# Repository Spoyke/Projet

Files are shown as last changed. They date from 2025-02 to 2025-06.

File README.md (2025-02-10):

# Projet
Ce projet vise à créer deux énigmes sur un cube. L'un comportera un message à déchiffrer un code et l'écrire sur un codex et le second consiste à aligner des miroirs pour diriger des faisceaux lasers sur des capteurs.  

Intro:
L’idée est de créer un cube comportant 4 énigmes permettant d’obtenir 3 clefs pour activer un mécanisme à la fin.
La Team A s’occupe de la face du haut, la Team B s’occupe d’une face latérale et la Team C nous nous occupons de deux face latérales et de la face ou l’on insère les clefs.
Notre première face comporte un codex et est relié à une seconde face qui est un parcours de lasers.

IMG CODEX

La partie avec le codex reprend des mécaniques simples mais efficaces des jeux d’énigmes. Cette partie du cube fera tout d’abord clignoter une LED. Et, un message codé se cache dans les clignotements de la LED. L’utilisateur devra donc décoder le message grâce à un tableau de correspondance inscrit quelque part sur le cube. Une fois le message décodé, le joueur n’a plus qu’à le reporter sur le codex de la face. Et si le message est correct, un mécanisme s’enclenche et débloque la seconde face de l’énigme avec les lasers. 

Techniquement, cette face comporte 2 éléments propres : une LED et un codex. La LED est directement reliée à une stm qui fera constamment clignoter le message. Et, le codex est constitué de plusieurs roues. Chacune des roues comprend une lettre du message. Si toutes les roues sont tournées dans le bon sens, un faisceau laser passe à travers ce dernier et est redirigé vers la seconde face de l’énigme. 

IMG LASER

La face avec les lasers comporte 4 lasers qui clignotent à différente fréquence invisible à l'œil nu afin de les différencier. Nous avons besoin de 4 capteurs capables d'identifier différents niveaux de clignotement.
Le but comme vous pouvez le voir sur l’image ci-dessus est de créer 4 parcours différents plus ou moins simple avec des obstacles pour ajouter de la difficulté aux parcours. 
Afin d’orienter les lasers nous utilisons des miroires, les tige qui s’enfonce dans le quadrillage seront crantée afin d'éviter une rotation sous le poids.(cela sera etudiee pour etre sur de l’utilité)

L’énigme une fois réussie ouvre une trappe pour avoir la clef, elle peut être résolution si et seulement si les lasers sont en face des bon capteurs.

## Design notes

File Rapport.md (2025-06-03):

# Partie informatique

## 1. Objectif général

Cette partie du projet vise à gérer la logique de l’énigme via un microcontrôleur STM32. Le programme contrôle une LED affichant un mot en morse, lit un phototransistor pour vérifier la position d’un "codex", et commande un moteur (via PWM) permettant l’ouverture d’une boîte contenant une clé.

## 2. Configuration matérielle

Avant le développement logiciel, une configuration matérielle du microcontrôleur est nécessaire en fonction des besoins du système.

### Ressources utilisées :

#### Configuration générale

| Fonction | Broche | Configuration | Détail |
|---|---|---|---|
| LED morse | PA10 | GPIO_Output | Contrôle de l'affichage en morse  |
| Bouton de déclenchement | PA4 | GPIO_Input | Détection de l'appui utilisateur |
| Lecture du phototransistor | PA3 | ADC | Vérification de la résolution du codex |
| Commande du moteur | PA9 | PWM | Contrôle de l'ouverture de la boîte |

#### Configuration des composants

Il y a deux timers dans le projet. Un (tim2) pour faire fonctionner le code. Nous verrons son utilité dans la partie "Structure logicielle". Le second timer (tim1) génère le signal PWM permettant de contrôler les moteurs. 

Le timer 2 est paramétré pour généré une interruption toute les millisecondes (PSC = 3 et ARR = 9999). Ce qui est largement suffisant pour notre programme qui dépend surtout de l'interaction avec l'utilisateur.

Tandis que le timer 1 est configuré pour générer un signal PWM sur le channel 2 (PA9) pour des raisons de débogage (PA8 soit channel 1 est aussi utilisé par la carte dans le mode debug). Par défaut, le timer possède un PSC de 3 et un ARR de 19999. Et, l'auto reload preload est activé.

L'adc est simplement activé sur IN8 (PA3).

## 3. Structure logicielle

Le programme fonctionne en simulant du multithreading. Chaque milliseconde, une interruption générée par le Timer 2 qui appelle successivement l'une des **4 fonctions du projet**, de manière cyclique.

### Les tâches sont les suivantes :

- **taskReadBtn**  
   Lit l’état du bouton utilisateur et met à jour la variable globale `motor_state`.

- **taskBlinkLed**  
   Gère l’affichage du message en morse via la LED, en fonction de `morse_btn_state`.

- **taskReadLed**  
   Lit la tension aux bornes du phototransistor via l’ADC. Si la tension dépasse un seuil, cela indique que le bon mot est affiché sur le codex.

-  **taskControlMotor**  
   Modifie le signal PWM selon l’état de l’énigme (`motor_state`), avec un délai d’une seconde pour éviter les activations accidentelles.

## 4. Détails de l’implémentation

### `main.c`

Le fichier "main" n'est utilisé uniquement pour initialiser les différent composants du projet : 

- Activation des interruptions (Timer 2)
- Lancement du signal PWM (Timer 1)

### `stm32l4xx_it.c`

Ce fichier comprend le cœur des fonctions du projet, exécuté à chaque interruption du Timer 2.

#### `taskReadBtn()`

Fonction simple mais essentielle :  
Elle lit l’état du bouton poussoir et met à jour la variable `morse_btn_state`. Cette variable déclenche ou interrompt la séquence Morse dans les autres fonctions.

#### `taskBlinkLed()`

Cette fonction affiche un mot en morse via une LED.  
- Des variables statiques gèrent le caractère affiché ainsi que sa durée d'exposition.
- À chaque appel, si le bouton a été pressé (`morse_btn_state == 1`), la LED clignote selon le code Morse définie dans une constante.
- En fin de message, les variables sont réinitialisées.

#### `taskReadLed()`

Fonction de lecture analogique :
- Lance une conversion ADC et attend la fin.
- Convertit la valeur lue (sur 12 bits, 0–4095) en tension via un produit en croix : $tension = \frac{100.Valeur~de~l'adc}{2^{12}}$. Ce qui permet d'avoir une valeur comprise entre 0 et 100 en sortie. On aurait pu multiplié par 5 pour obtenir la tensions aux bornes du photo-transistor en sortie, le choix de multiplié par 100 est purement arbitraire.
- Si la tension dépasse un seuil défini (ici 90), la variable globale `motor_state` est mise à 1 (sinon 0), indiquant que le codex a été résolu.

#### `taskControlMotor()`

Cette fonction gère le moteur via la PWM :
- Si `motor_state` passe à 1, on lance un compte à rebours d'une seconde avant de modifier le signal PWM.
- Cela évite que l’utilisateur n’active le moteur par hasard lors de la rotation du codex.
- Le PWM est modifié via `__HAL_TIM_SET_COMPARE()` en fonction de l’état validé.

Le rôle des moteurs dans l'énigme étant de simplement ouvrir ou fermé le prix. Ces derniers ne se situeront qu'au deux extrêmes possibles (0 ou 180°). C'est pourquoi, avec `__HAL_TIM_SET_COMPARE()`, nous paramétrons le signal pour qu'il soit sur un des deux extrêmes, c'est-à-dire une largeur de crénau de 10ms ou de 20ms.

NB : A savoir que lorsque l'on flash le code sur le microprocesseur, il faut ensuite couper l'alimentation de la carte avant de la remettre pour que le code prenne effet.

# Concernant le PCB

## 1. Enjeux du PCB

Pour le projet, nous avons besoin de créer un PCB qui respecte certaines conditions, comme le fait que nous prévoyons d’utiliser deux faces du cube et que nous sommes dans une démarche écologique, donc sans gaspillage.
Nous allons également avoir besoin d’utiliser des composants sans forcément les relier directement au PCB.

## 2. Disposition sur le PCB

### Pour la composition du PCB, nous avons besoin de plusieurs éléments :

- **Le microprocesseur**  
   Nous avons décidé d’utiliser le `STM32L412KBT6`, car il possède suffisamment de pins pour notre projet et nous permet de rester sur la gamme STM. Il sera accompagné de son connecteur afin de pouvoir téléverser le code.\
  _Nous utiliserons un réseau de trois condensateurs, 4,7 µF, 100 nF, et 100 nF, pour découpler l’alimentation générale.
Nous filtrerons également l’alimentation à l’aide d’un filtre LC, afin de la stabiliser. Ce filtre sera composé d’une inductance de 39 nH et de deux condensateurs de 1 µF et 10 nF, dans le but de filtrer les hautes fréquences et les parasites liés à la masse._

- **Les lasers**  
   Nous aurons besoin d’une partie dédiée aux lasers et à leurs récepteurs (utilisés dans la deuxième énigme). Le but de cette énigme est d’utiliser un jeu de miroirs pour rediriger les faisceaux vers leurs récepteurs, afin de résoudre l’énigme.\
   _Les lasers utilisé sont des `VMA434` et on besoins simplement du résistance de 270 ohms sur le pin d'information._

- **Le régulateur de tension**  
   Nous avons également besoin d’un régulateur de tension pour l’alimentation du PCB, nous utilisons un LDO, le `BU33SD5WG-TR`.\
   _Nous relierons le GND et le Vout par un condensateur de 1 µF, de même pour le Vin et le GND. Le Vin sera alimenté en 5 V et le Vout délivrera du 3,3 V._

- **Une seconde PCB sera fixée sur une autre face pour le fonctionnement du codex.**  
   Elle comprendra une LED (émetteur) qui, une fois le bon code trouvé sur notre codex, viendra éclairer un phototransistor (récepteur) en passant à travers de petits trous alignés dans les roues du codex. Il y aura également une LED qui affichera le code morse afin que l’utilisateur puisse le déchiffrer.\
  _Une résistance de 10 kΩ sera utilisée pour le phototransistor, ainsi que des résistances d’adaptation pour les LED : une de 580 Ω reliée à l’alimentation, et une autre de 420 Ω reliée au GND._

- **Deux boutons**  
   Un pour réinitialiser le code morse, et un autre pour réinitialiser le microcontrôleur (et donc les lasers également).\
   _Ils seront en montage push-pull, avec des resistance de 120 Ω._

- **Deux Servomoteurs**  
   Le premier permettra l’ouverture de la trappe pour accéder à la clé après la résolution de nos énigmes.
   Le second servira à ouvrir la boîte une fois toutes les énigmes résolues.
   Il suffit qu’ils tournent à 180° pour permettre une ouverture optimale.

- **Les clefs**  
   Nous avons besoin d’un accès au 5V et au GND afin d’interconnecter les différentes clés entre elles.

- **Infos importantes**  
   Comme tous les composants ne sont pas directement connectés au PCB, car ils doivent être placés à différents endroits, nous utilisons des connecteurs à la place des composants pour faciliter leur déport.\
  Des trous de fixation sont également prévus afin de pouvoir fixer nos PCB.

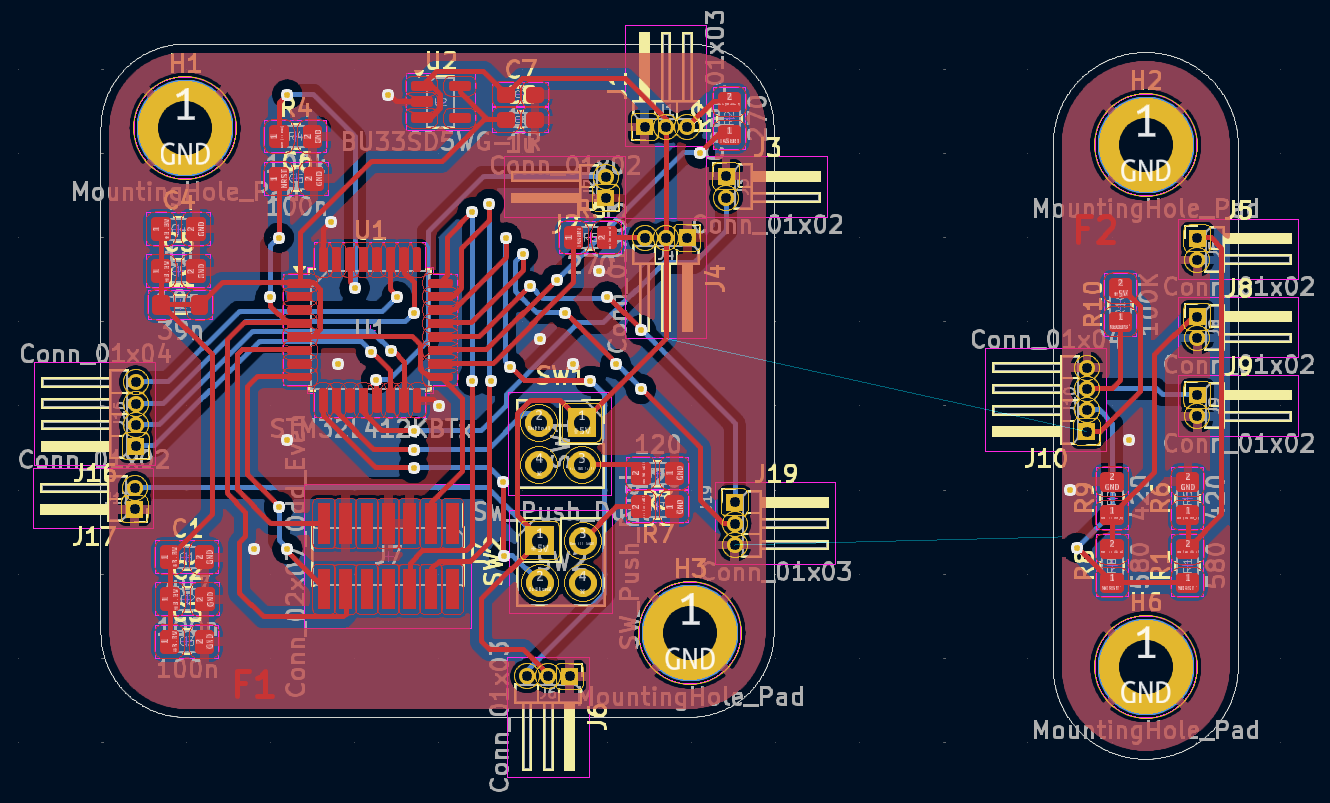
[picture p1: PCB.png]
 

# 3. Conception mécanique et assemblage

## 3.1 Objectif de conception

L’un des objectifs majeurs de notre projet était de rendre notre dispositif **totalement reproductible** sans nécessiter de machines industrielles. Pour cela, nous avons choisi de ne faire appel qu’à une **imprimante 3D**, aujourd’hui couramment disponible dans les établissements scolaires et chez les particuliers. Ce choix garantit une accessibilité maximale et facilite la réplicabilité du projet.

## 3.2 Outils et logiciels utilisés

La modélisation 3D a été réalisée à l’aide de **Tinkercad**, un outil simple et intuitif, parfaitement adapté pour concevoir des pièces rapidement, même sans expérience avancée en modélisation. Malgré ses limitations par rapport à des logiciels professionnels comme SolidWorks, Tinkercad s’est avéré suffisant pour notre projet.

## 3.3 Le codex

Le **codex** est le cœur de notre énigme : il est constitué de **six disques rotatifs**, chacun comportant un **trou** positionné avec précision. Lorsque les disques sont alignés sur les bonnes lettres, les trous laissent passer la lumière d’une **LED émettrice** jusqu’à un **phototransistor récepteur**.

- Le mot utilisé dans cette version du codex est **"cadena"** (sans "s", une petite omission volontairement conservée).
- Chaque disque possède **26 crans**, correspondant aux **26 lettres de l’alphabet** .

Lorsque le bon mot est aligné, la LED éclaire le phototransistor, ce qui déclenche l’ouverture de la trappe contenant la **clé**.

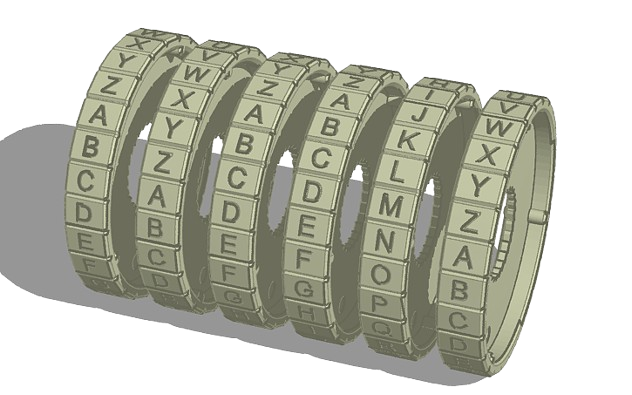
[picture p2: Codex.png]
 

## 3.4 Mécanisme d’ouverture motorisé

L’ouverture de la trappe se fait via un **servomoteur**, activé dès que le codex valide la solution. Pour convertir le mouvement du servomoteur en une action mécanique fiable, nous avons conçu un **système d’engrenages** également imprimé en 3D.

Ce mécanisme permet :
- Une **transmission fiable** de l’effort moteur.
- Une **ouverture douce** de la trappe.
- Une **compatibilité mécanique totale** avec les autres composants imprimés.

Bien que nous ne disposions pas de logiciels de simulation avancés (comme SolidWorks) pour tester virtuellement ce système, nous avons pu valider son fonctionnement par des essais physiques et des ajustements progressifs.

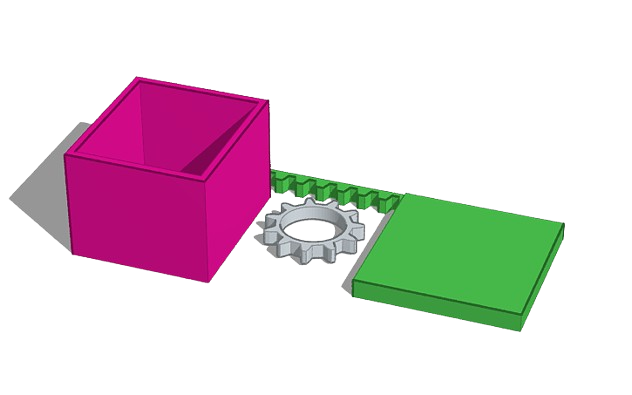
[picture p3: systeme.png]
 

## 3.5 Boîte en bois découpée au laser

Pour l’enceinte du projet, nous avons opté pour une **boîte en bois**, réalisée par **découpe laser**. Ce choix offre une structure rigide, écologique, et facilement personnalisable.

- Nous avons utilisé le site **MakerBox** pour générer automatiquement les plans de la boîte selon nos dimensions (ici, **30 × 30 cm**).
- Les fichiers SVG générés ont été modifiés avec **Inkscape**, un logiciel libre de dessin vectoriel, afin de répondre aux besoins spécifiques de notre groupe et des autres équipes travaillant sur le projet.

Grâce à cette approche, nous avons obtenu une boîte à la fois **fonctionnelle**, **esthétique** et **parfaitement adaptée** à notre structure interne.

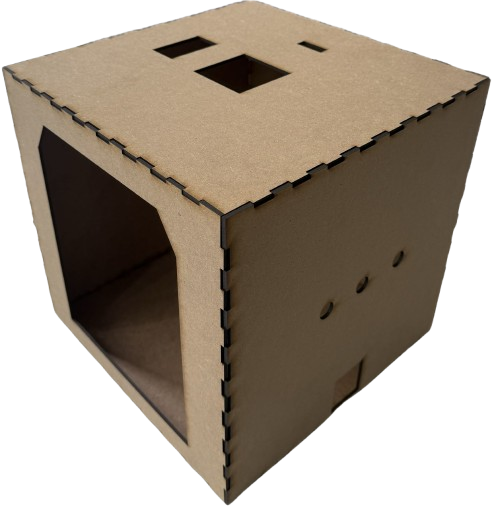
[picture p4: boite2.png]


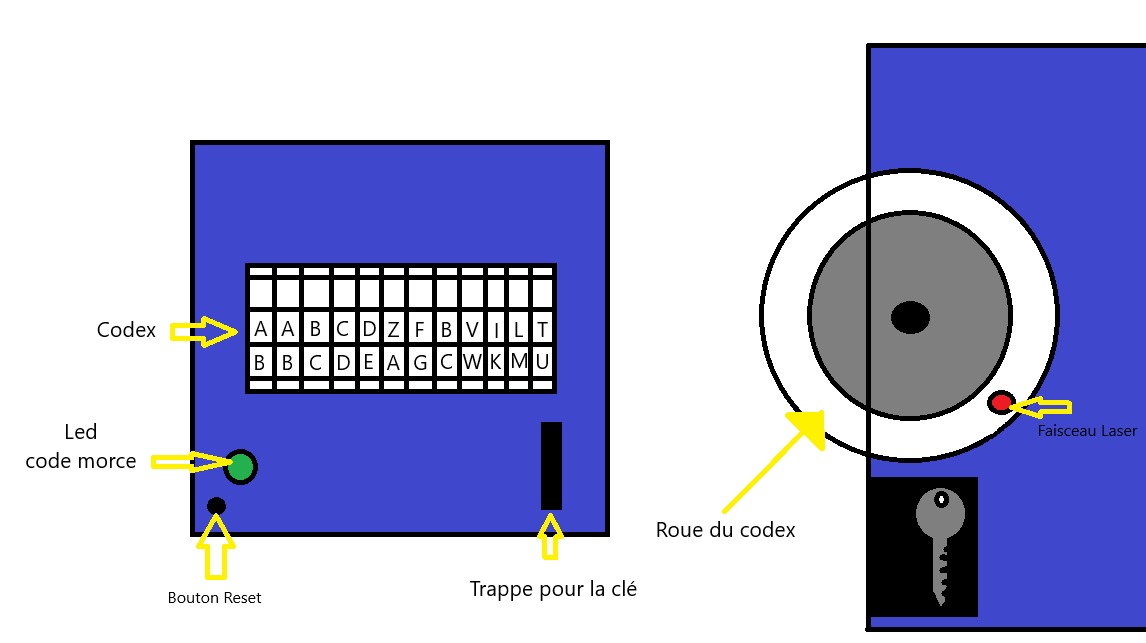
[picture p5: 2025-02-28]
Schéma_projet_codex.jpg

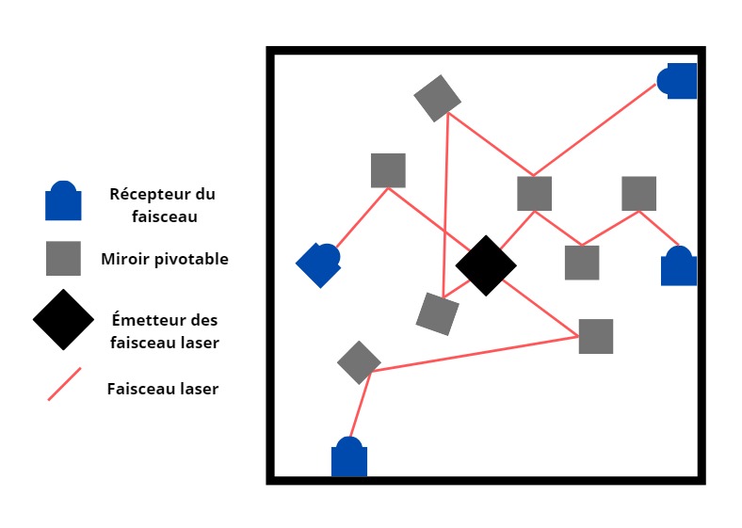
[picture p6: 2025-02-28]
Schéma_projet_laser.jpg

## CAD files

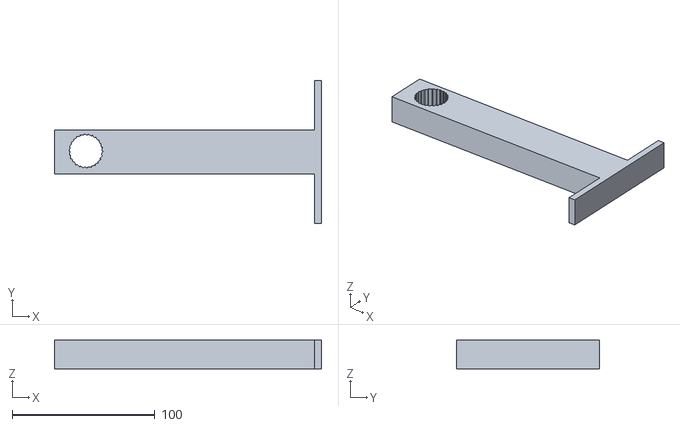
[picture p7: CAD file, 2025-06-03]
Roue Codex (1).stl
187.0 x 100.0 x 20.0

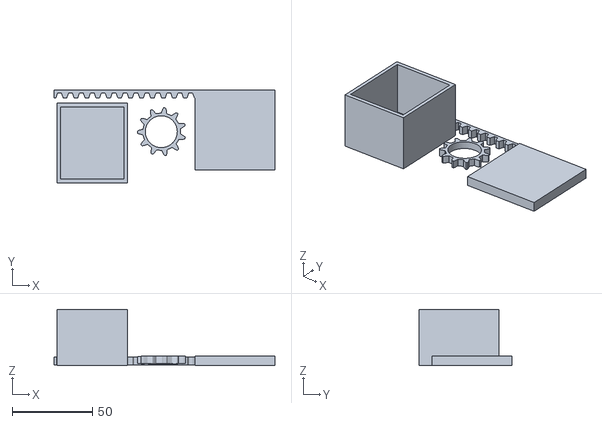
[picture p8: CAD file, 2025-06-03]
Systeme_ouverture.stl
138.0 x 58.0 x 35.0

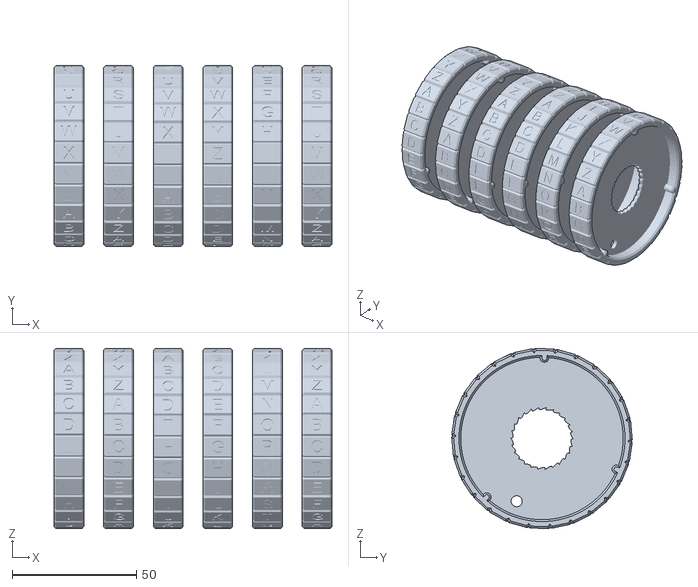
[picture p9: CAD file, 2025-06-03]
Codex_Cadena.stl
112.0 x 72.8 x 72.6

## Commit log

2025-06-03 Update Rapport.md
    PCB push1
2025-06-03 Update Rapport.md
    PCB push2
2025-06-03 Update Rapport.md
    PCB push3
